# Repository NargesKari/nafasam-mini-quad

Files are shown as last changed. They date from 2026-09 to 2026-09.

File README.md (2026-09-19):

# nafasam-mini-quad

A phone-to-ESP32 wireless control link for a quadcopter, built around a hand-specified binary protocol with a checksum, a kill switch, and a failsafe — the network layer a drone project needs before the flight controller is worth writing.

## What it does

- Runs the ESP32 as an open WiFi access point (`nafasm`) serving a touch-control web page straight from flash, so any phone can connect with no app install.
- The page has two virtual joysticks (left: throttle/yaw, right: pitch/roll), an ARM/DISARM button, status lights (link / IMU / armed) and a help panel. It polls `GET /control` every 100 ms.
- A 200 Hz FreeRTOS task on core 0 reads the MPU6050 directly over its registers (no library), estimates roll/pitch with a complementary filter, runs PID stabilisation, mixes for an X-configuration quad and drives four transistor-switched brushed motors with PWM.
- Safety: failsafe disarm after 500 ms of silence, arm refused with throttle up, motors off on any IMU error, crash-angle disarm.

See `docs/protocol.md` for the exact contract.

## Repo layout

- `firmware/nafasam_quad/` - Arduino sketch (`.ino`, `config.h` pins/PID/safety, `mpu6050.*` driver, generated `web_page.h`)
- `web/public/index.html` - control page (single source of truth)
- `hardware/` - schematics, PCB, datasheets, mechanical parts
- `docs/` - protocol
- `scripts/generate_web_header.py` - embeds the page into the firmware

## Getting started

Arduino IDE with the ESP32 core v3.x (no extra libraries), open `firmware/nafasam_quad/nafasam_quad.ino`, select an ESP32 Dev Module, upload. Power the drone flat and still: the gyro calibrates at boot.

If you edit the control page:

```bash
python3 scripts/generate_web_header.py   # then re-flash
```

Connect to the `nafasm` WiFi and open `http://192.168.4.1/`.

**First power-up: remove the propellers** and check each motor's direction and the sign of the stabilisation on the bench before any flight.

<!-- add screenshot/demo here -->

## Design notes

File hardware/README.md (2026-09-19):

# hardware

Everything physical: circuits, PCBs, parts.

- `schematics/` - motor driver circuits, power distribution, ESP32 wiring (KiCad/Fritzing/PDF exports)
- `pcb/` - board layouts and Gerber files
- `datasheets/` - ESP32, IMU, transistor, motor, battery datasheets
- `mechanical/` - frame, motor mounts, 3D-printable parts (STL/STEP)

# Wiring guide

Board: generic **ESP32-WROOM-32 DevKit, 30 pins**. Pin names below are the labels printed on the board, with the GPIO number in brackets. The source of truth for pins is `firmware/nafasam_quad/config.h`.

## 1. ESP32 <-> MPU6050 (GY-521 module)

| MPU6050 pin | ESP32 pin (board label) | Notes |
|---|---|---|
| VCC | **3V3** | 3.3 V, not VIN |
| GND | **GND** | |
| SDA | **RX2** (GPIO16) | I2C data |
| SCL | **TX2** (GPIO17) | I2C clock |
| AD0 | GND (or leave open) | I2C address 0x68 |
| INT, XDA, XCL | not connected | unused |

Pull-ups: one resistor from **SDA (GPIO16) to 3V3** and one from **SCL (GPIO17) to 3V3**, between 2.2k and 10k ideally (27k also works at the 100 kHz the firmware uses). Many GY-521 modules already include pull-ups; adding external ones in parallel is fine.

Mount the module flat, chip facing up, with the module's **X axis pointing to the nose** and **Y to the left**. If it is mounted differently the stabilisation signs must be remapped in `flightTask()`.

## 2. ESP32 -> motor drivers (PWM outputs)

Each motor has its own transistor stage. The ESP32 pin goes to the transistor **base/gate through a resistor**.

| Motor | Position | Spin | ESP32 pin (board label) |
|---|---|---|---|
| FL | front-left | CW | **D23** (GPIO23) |
| FR | front-right | CCW | **D5** (GPIO5) |
| RL | rear-left | CCW | **D18** (GPIO18) |
| RR | rear-right | CW | **D13** (GPIO13) |

Per-motor circuit (low-side switch):

```
Battery + ----------------+----------------+
                          |                |
                       [Motor]        [Diode] (flyback, cathode to battery +)
                          |                |
                          +----------------+
                          |
                  collector/drain
ESP32 GPIO --[R base]-- base/gate      transistor
                  emitter/source
                          |
Battery - / common GND ---+
```

Also add:
- **Base/gate resistor** (about 1k for a BJT is typical; size it for your transistor and motor current) from GPIO to base/gate.
- **Pull-down** (about 10k) from base/gate to GND. This matters most on **GPIO5**, a boot-strapping pin that can pulse during boot and would briefly spin the motor.
- **Flyback diode** across every motor (anode on the transistor side). Without it the motor's voltage spikes can destroy the transistor and reset the ESP32.
- **Noise-filter capacitor** across each motor terminals (as planned; ceramic 100 nF is typical).
- Make sure each transistor can handle the motor's **stall current**, with margin.

Spin direction is fixed by how each motor is wired/mounted (the firmware never reverses a motor). If a motor spins the wrong way, swap its two motor wires.

## 3. Battery

The battery type is not fixed by the code, so pick the option that matches yours:

| Connection | Goes to |
|---|---|
| Battery **+** | motor **+** terminals (all four, via a fuse/switch ideally) and the ESP32 power input (see below) |
| Battery **-** | **ESP32 GND**, MPU6050 GND and all transistor emitters/sources |

**All grounds must be common** (battery -, ESP32 GND, MPU6050 GND, every transistor emitter). If they are not joined, the PWM signal has no reference and the motors will misbehave.

Powering the ESP32:
- Battery gives **about 5 V** (e.g. a 5 V regulator/boost stage, or USB power bank): connect to **VIN** (5 V) and GND.
- Battery is a **single 3.7 V LiPo**: the DevKit's on-board regulator needs about 5 V at VIN, so use a boost converter to 5 V into **VIN**, or a 3.3 V regulated supply into the **3V3** pin (bypasses the on-board regulator; never do both at once).
- Do **not** connect a battery above 6 V directly to VIN.
- Never connect USB and an external supply to VIN at the same time without a diode.

Motor current spikes can brown out the ESP32. Put a **large capacitor (about 470 uF or more)** across the battery rails near the ESP32 and, if resets still occur, a separate supply/regulator for the ESP32.

## 4. Quick checklist before first power-up

1. Remove the propellers.
2. Check continuity: MPU SDA -> GPIO16, SCL -> GPIO17, and each motor pin against the table above.
3. Confirm no short between battery + and -, and that all grounds are joined.
4. Power on with the drone flat and still (the gyro calibrates at boot); wait for the **IMU** light on the web page.
5. Connect to the `nafasm` WiFi, open `192.168.4.1`, and test each motor with low throttle before flying.

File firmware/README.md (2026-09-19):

# firmware

ESP32-S3 firmware for the Nafasam Mini Quadcopter.

- [`nafasam_quad/`](nafasam_quad/): Arduino sketch directory. Open [`nafasam_quad/nafasam_quad.ino`](nafasam_quad/nafasam_quad.ino) in Arduino IDE.
- [`nafasam_quad/README.md`](nafasam_quad/README.md): **Hardware pinout and port connection guide** for ESP32-S3, MPU-6050, motors, battery ADC, and programmer.
- [`nafasam_quad/config.h`](nafasam_quad/config.h): Tunable flight control, PID, PWM, and Wi-Fi constants.
- [`nafasam_quad/web_page.h`](nafasam_quad/web_page.h): Auto-generated web interface header (regenerate with `python3 scripts/generate_web_header.py`).

No external Arduino libraries required (uses native ESP32 core v3.x: `WiFi`, `Wire`, `esp_http_server`).

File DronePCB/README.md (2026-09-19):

# DroneFC — engineering prototype A0

Open **design/DroneFC.kicad_pro** in KiCad 10. The project includes an editable seven-page schematic, a four-layer PCB, and local symbol/footprint libraries. The local libraries make the project portable.

**This is a prototype design, not a flight-tested or production-qualified controller. Read reports/validation-summary.json for the latest checks. Do not fabricate from an intermediate routing file.**

## Design choices

- ESP32-S3-MINI-1-N4R2: soldered module with 4 MB flash and 2 MB PSRAM. The module integrates RF circuitry and a PCB antenna. A bare ESP32 silicon implementation would require additional RF, clock and memory design.
- MPU-6050 bare QFN chip, I2C address 0x68. The auxiliary sensor bus and reserved pins are intentionally unused.
- Four AO3400A low-side motor switches, four SS34 flyback diodes, 100-ohm gate resistors, and 10-kilohm gate-to-source pulldowns.
- One 700 mAh, 20C, 1S LiPo. The advertised continuous discharge calculation is 0.7 Ah × 20 = 14 A; it does not establish the battery's real internal resistance or transient capability.
- TPS63021 fixed 3.3 V buck-boost converter for electronics, with a 1.5 uH inductor, two 10 uF input capacitors, three 22 uF output capacitors, and 100 nF control-supply bypass. Target electronics load is up to 1 A at battery voltage ≥3.0 V, subject to thermal/transient testing.
- TLV70028 and TLV70012 regulators provide the camera's 2.8 V and 1.2 V rails.
- A 10-ohm/1 uF filter feeds the IMU; local VDD, VLOGIC, REGOUT and CPOUT capacitors are 100 nF, 10 nF, 100 nF and 2.2 nF respectively. CPOUT uses a 50 V-rated capacitor.
- No charging circuit, SD card slot, USB socket, development-board headers, or flash LED. Programming uses solder pads and an external 3.3 V UART adapter.

## Mechanical and stackup intent

PCB outline: **50 × 50 mm**, nominal **0.8 mm** FR4, four copper layers. This is the first layout size, not a claim of minimum achievable size or mass. The antenna end of the ESP32 module extends beyond the PCB outline, so the assembled envelope is larger than 50 mm in that direction.

Layers: front signals/components, inner ground, inner battery distribution, back signals. Two camera signals (PCLK and RESET) also use the battery layer with clearance around them; the ground plane remains continuous. Ground and battery use solid connections to the inner planes. The motor-current pads use multiple vias. The final copper thickness, stackup, minimum spacing and via process must be agreed with the board manufacturer. The thermal/current assumptions require approximately 35 um finished copper on the power planes and outer layers; do not silently substitute thinner inner copper.

U2 uses the local TI_DSJ14_TPS63021 footprint, with a 1.58 × 2.85 mm exposed ground pad checked against TI drawing 4208549-3/E. Its peripheral lands are slightly enlarged relative to TI's example. Segmented paste covers approximately 65% of the exposed pad. Have the assembler qualify stencil thickness and via-in-pad treatment, including the module ground pads and the regulator ground connection. This is not a qualified assembly process.

Four M2 clearance holes use a nominal 44 × 26 mm spacing. Confirm that this pattern fits the frame. Keep the module antenna free of battery, carbon fibre, motors and wiring. The PCB is a controller mounted to a frame, not a structural motor-support plate.

## Camera compatibility

J3 uses **Hirose FH12-24S-0.5SH(55)**, a 24-pin, 0.5 mm pitch, bottom-contact FPC connector. Its electrical pinout follows the OV2640 interface shown in the AI-Thinker ESP32-CAM v1.6 reference schematic archived in references/ESP32_CAM_V1.6.pdf.

Buy only a camera flex assembly with this exact pinout. “OV2640” alone does not specify the connector pinout, contact side, flex thickness, lens clearance or power rails. The final camera assembly has not been selected from a seller. **The seller's flex drawing must be checked before fabrication.** The provided connector is not a generic plug for every ESP32 camera.

The camera's Y2–Y9 lines form D0–D7. Y0/Y1 and pin24 are unused. Camera I/O runs at 3.3 V, analog at 2.8 V and core at 1.2 V, consistent with the referenced assembly. See pin-map.json for the exact connections.

## Motor and battery connections

J2 pin1 is battery positive, pin2 is ground. J4–J7 pin1 is motor positive (VBAT), pin2 is the switched motor negative. SS34 cathodes connect to VBAT and anodes to motor negative. AO3400A pin1 is gate, pin2 source, pin3 drain.

**C101–C104 are off-board components:** solder one 100 nF, 16 V ceramic directly across each motor's terminals. Their presence in the BOM is intentional; they have no PCB footprints. C25–C28 are separate local 10 uF rail-decoupling capacitors near the motor drivers. C11 is a low-ESR 220 uF bulk capacitor. Its exact manufacturer part number, ripple rating, ESR and height remain a sourcing check; its allocated package is 6.3 × 5.8 mm.

The linked ECA listing describes 1.74 A as maximum loaded current. Four motors at that figure draw 6.96 A, excluding electronics. Stall/startup current is not specified by that figure. Measure it with current limiting and appropriate test equipment. Do not infer MOSFET, diode or battery stall survival from their headline current ratings.

AO3400A's specified 48 milliohm maximum at 2.5 V gate drive gives approximately 0.145 W conduction loss per motor at 1.74 A and continuous on-time at the datasheet reference temperature. Hot resistance, switching loss and flyback-diode dissipation increase the actual thermal load. This calculation is not a thermal qualification.

There is no reverse-polarity protection, battery charger or hardware LiPo cutoff on this board. Confirm polarity before connection, use an external 1S charger, and disconnect the battery after use. Battery voltage monitoring is available to firmware through a 100k/100k divider and 100 nF filter. The nominal ADC scale factor is 2, with calibration still required.

## Programming and firmware requirements

J1 pads, in order: GND, 3V3, UART_TX, UART_RX, BOOT, ESP_EN. Use **3.3 V logic**. Connect adapter TX to board RX and adapter RX to board TX. With the battery powering the board, use J1's 3V3 as a reference only; do not connect a second driven supply. Hold BOOT low while pulsing ESP_EN low to enter the ROM loader.

The included firmware header only defines hardware pins. It is not flight-control firmware. Before flying, implement and test local IMU sampling, calibration, attitude estimation, motor mixing, arming, link-loss response, watchdog response and low-battery handling. Flight stabilization must run locally; Wi-Fi carries commands/video rather than providing the timing of the stabilization loop. Keep camera processing from delaying the control loop.

All motor PWM outputs must initialize low. Establish a measured control-loop budget with camera streaming enabled. A fresh 1S cell reaches 4.2 V; the motors are listed as nominal 3.7 V. Confirm their permitted supply and use a battery-aware duty limit as appropriate. An average-voltage duty limit does not limit instantaneous stall current.

## Bench acceptance before flight

1. Inspect soldering and check supply resistance and polarity without battery connected. Start on a current-limited supply with motors disconnected.
2. Sweep battery input over the intended operating range and verify 3.3 V, 2.8 V, 1.2 V and IMU supply voltage, including camera/Wi-Fi transients.
3. Read MPU-6050 identity, check stationary gyro/accelerometer readings and confirm axis orientation. Check camera frames and the UART boot process.
4. With propellers removed, verify each motor remains off at boot/reset and test PWM individually. Then use a restrained thrust test to establish propeller load, startup current, voltage sag and component temperature.
5. Verify arming, loss-of-link response, watchdog reset and low-battery behavior before any flight. Establish thrust margin using the actual all-up mass.

## Sources

- [ESP32-S3-MINI module datasheet](https://documentation.espressif.com/esp32-s3-mini-1_mini-1u_datasheet_en.html)
- [Espressif camera driver and supported sensors](https://github.com/espressif/esp32-camera)
- [AI-Thinker ESP32-CAM v1.6 reference schematic, hosted by Seeed](https://github.com/SeeedDocument/forum_doc/blob/master/reg/ESP32_CAM_V1.6.pdf)
- [MPU-6000/6050 manufacturer specification](https://invensense.tdk.com/wp-content/uploads/2015/02/MPU-6000-Datasheet.pdf)
- [AO3400A manufacturer specifications](https://www.aosmd.com/products/mosfets/low-voltage-mosfets-12v-30v/ao3400a)
- [TPS63020/21 manufacturer datasheet](https://www.ti.com/lit/ds/symlink/tps63020.pdf)
- [XFL4020 inductor drawing](https://www.coilcraft.com/getmedia/50632d43-da1b-4cdb-8ab4-3029cab51df3/xfl4020.pdf)
- [Hirose camera connector](https://www.hirose.com/product/p/CL0586-0521-0-55)
- [ECA 8520 motor listing](https://eshop.eca.ir/موتور-coreless/6933-موتور-coreless-سایز-8520.html)

## Project contents

- design/DroneFC.kicad_pro, .kicad_sch and .kicad_pcb: editable KiCad project.
- BOM.csv: individual component values, packages and sourcing notes.
- design_manifest.json: component/net design intent; the PCB contains the final adjusted placement.
- pin-map.json and drone_pins.h: interface mapping.
- reports/: electrical, physical and connectivity checks.
- preview/: schematic and board previews.
- tools/ (working directory only, omitted from the delivery archive): development helpers and project-local routing tools. These contain intermediate design assumptions. Re-running build_design.py with --pcb replaces the board with its initial unrouted placement. Preserve the final PCB and local libraries before regenerating.

## Validation and delivery

The final routed PCB passes the configured KiCad electrical and physical checks with zero reported violations and zero unconnected items. An independent exported-netlist comparison matches all 240 connected component pins between schematic and PCB. The JSON reports list the checks that KiCad ignores under the project settings; a clean report does not establish thermal performance, signal integrity or flight suitability.

DroneFC-prototype-A0.zip contains the editable design, local libraries, component list, pin mapping, final reports and previews. No manufacturing release is included: camera flex compatibility, C11 sourcing, assembly process and manufacturer stackup still require confirmation. Actual motor startup/stall current, rail transients, thermal behavior and thrust margin require hardware tests. Board mass and efficiency have not been measured.

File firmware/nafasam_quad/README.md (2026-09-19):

# Nafasam Mini Quad - Firmware & Hardware Connection Guide

This directory contains the Arduino flight controller sketch for the **Nafasam Mini Quadcopter**, designed for the **ESP32-S3-MINI-1-N4R2** microcontroller and the **DroneFC PCB Revision A0**.

---

## 1. Physical Layout & Motor Orientation

The quadcopter uses an **X-Configuration**. The front of the drone corresponds to the top edge of the DroneFC PCB where the ESP32-S3 antenna extends.

```text
                  FRONT / NOSE
             (ESP32 Antenna Side)
                      ▲
                      │
     [Motor 1: FL]          [Motor 2: FR]
        GPIO 39                GPIO 40
        (CW ↻)                 (CCW ↺)
            \                /
             \    [U3]      /
              \  MPU-6050  /
               \  Center  /
                \        /
                 \      /
     [Motor 3: RL]          [Motor 4: RR]
        GPIO 41                GPIO 42
        (CCW ↺)                (CW ↻)
                      │
                      ▼
                 REAR / TAIL
            (Camera FPC Connector)
```

---

## 2. Complete Port & Pin Mapping Table

| Subsystem | Function / Signal | ESP32-S3 GPIO | PCB Net | Connector / Part Reference | Notes |
|---|---|---|---|---|---|
| **Motors (8520)** | Motor 1: Front-Left (FL) | **GPIO 39** | `PWM1` | `J4` / `Q1` (AO3400A) | Spin: Clockwise (**CW**). Switched to `MOTOR1_NEG`. |
| **Motors (8520)** | Motor 2: Front-Right (FR) | **GPIO 40** | `PWM2` | `J5` / `Q2` (AO3400A) | Spin: Counter-Clockwise (**CCW**). Switched to `MOTOR2_NEG`. |
| **Motors (8520)** | Motor 3: Rear-Left (RL) | **GPIO 41** | `PWM3` | `J6` / `Q3` (AO3400A) | Spin: Counter-Clockwise (**CCW**). Switched to `MOTOR3_NEG`. |
| **Motors (8520)** | Motor 4: Rear-Right (RR) | **GPIO 42** | `PWM4` | `J7` / `Q4` (AO3400A) | Spin: Clockwise (**CW**). Switched to `MOTOR4_NEG`. |
| **IMU (MPU-6050)** | I2C Serial Data (SDA) | **GPIO 33** | `IMU_SDA` | `U3` Pin 24 | Dedicated I2C bus with pull-up resistor. |
| **IMU (MPU-6050)** | I2C Serial Clock (SCL) | **GPIO 34** | `IMU_SCL` | `U3` Pin 23 | Dedicated I2C clock (400 kHz Fast-Mode). |
| **IMU (MPU-6050)** | Interrupt Line (INT) | **GPIO 21** | `IMU_INT` | `U3` Pin 12 | Active-high motion interrupt. |
| **Battery Monitor** | 1S LiPo Sense (ADC) | **GPIO 1** | `VBAT_SENSE` | `R2`/`R3` Voltage Divider | 100k / 100k divider (2:1 ratio). Max 4.2V $\rightarrow$ 2.1V at ADC. |
| **UART Programmer** | Transmit (TXD) | **GPIO 43** | `UART_TX` | `J1` Pad 3 | Connect to external 3.3V UART adapter **RX**. |
| **UART Programmer** | Receive (RXD) | **GPIO 44** | `UART_RX` | `J1` Pad 4 | Connect to external 3.3V UART adapter **TX**. |
| **UART Programmer** | Boot Mode Button/Pad | **GPIO 0** | `BOOT` | `J1` Pad 5 | Hold LOW while pulsing `ESP_EN` to flash. |
| **UART Programmer** | Chip Enable / Reset | `ESP_EN` | `ESP_EN` | `J1` Pad 6 | Pull LOW briefly to reset ESP32. |
| **Power Supply** | Main System 3.3V | `3V3` | `3V3` | `U2` (TPS63021) | Buck-boost converter output feeding ESP32 & sensors. |
| **Power Supply** | Common Ground | `GND` | `GND` | All GND pads | Ground plane common to battery, MCU, IMU, and MOSFET sources. |

---

## 3. Subsystem Wiring & Connection Details

### 3.1 8520 Coreless Brushed Motor Driver Circuit
Each motor is driven by a low-side AO3400A N-Channel MOSFET:
- **Gate**: Driven by ESP32-S3 GPIO via a $100\,\Omega$ series resistor (`R1`, `R18`, `R19`, `R20`), with a $10\,\text{k}\Omega$ pull-down to GND.
- **Drain**: Connects to the motor negative terminal (`MOTORx_NEG`).
- **Source**: Directly connected to solid board ground (`GND`).
- **Flyback Diode**: An SS34 Schottky diode is connected in parallel with each motor (Cathode to `VBAT`, Anode to `MOTORx_NEG`) to absorb inductive kickback spikes.
- **RF Noise Filter**: Solder a $100\,\text{nF}$, $16\,\text{V}$ ceramic capacitor (`C101`–`C104`) directly across the terminal wires of each 8520 motor.

### 3.2 InvenSense MPU-6050 IMU
- **I2C Address**: `0x68` (Pin `AD0` connected to `GND`).
- **Orientation on PCB**:
  - `+X` points to **Right**
  - `+Y` points to **Forward / Nose**
  - `+Z` points **Up**
- **Power**: Filtered `3V3` rail via a $10\,\Omega$ resistor and local decoupling capacitors ($100\,\text{nF}$ + $1\,\mu\text{F}$).

### 3.3 Battery Voltage Measurement
- Connect 1S LiPo battery positive terminal to `J2` Pin 1 (`VBAT`) and negative terminal to `J2` Pin 2 (`GND`).
- `VBAT_SENSE` routes through a 2:1 resistive voltage divider ($R_1 = 100\,\text{k}\Omega$, $R_2 = 100\,\text{k}\Omega$, filtered by a $100\,\text{nF}$ capacitor).
- Calculation in firmware:
  $$\text{Voltage} = \frac{\text{analogReadMilliVolts}(1) \times 2.0}{1000}$$

### 3.4 Programmer Pads (`J1`)
The board has a 6-pad programming interface for an external 3.3V USB-to-UART adapter:

```text
 Pad 1: GND      ─── Connect to Programmer GND
 Pad 2: 3V3      ─── Reference ONLY (Do NOT supply external power when battery is connected)
 Pad 3: UART_TX  ─── Connect to Programmer RX
 Pad 4: UART_RX  ─── Connect to Programmer TX
 Pad 5: BOOT     ─── Hold to GND while resetting to enter download mode
 Pad 6: ESP_EN   ─── Pull to GND briefly to reset the MCU
```

---

## 4. Arduino IDE Upload Instructions

1. Open `nafasam_quad.ino` in Arduino IDE 2.x.
2. Under **Tools $\rightarrow$ Board $\rightarrow$ esp32**, select **ESP32S3 Dev Module**.
3. Recommended settings:
   - **Flash Size**: `4MB (32Mb)`
   - **PSRAM**: `OPI PSRAM` (or Disabled if unused)
   - **Upload Speed**: `115200` or `921600`
   - **USB Mode**: `Hardware CDC and JTAG`
4. Connect programmer pads (`TX`, `RX`, `GND`). Hold `BOOT` low, pulse `ESP_EN` low, release `BOOT`, then click **Upload**.

---

## 5. First Flight Bench Acceptance Checklist

> [!CAUTION]
> **ALWAYS REMOVE ALL PROPELLERS** during bench testing and calibration!

1. **Visual & Continuity Inspection**:
   - Verify no short circuit between `VBAT` and `GND`.
   - Verify continuity on motor gate pins and IMU `SDA` (GPIO 33), `SCL` (GPIO 34).
2. **Boot IMU Calibration**:
   - Place the drone completely **flat and still** before applying battery power.
   - The gyro automatically averages 300 samples to establish bias offsets. The `IMU` indicator will turn green once calibration passes.
3. **Wi-Fi Connection**:
   - On your smartphone, connect to the Wi-Fi access point: **`Nafasam`** (open network).
   - Navigate to `http://192.168.4.1/`.
4. **Motor Spin Test**:
   - Arm the quad at zero throttle.
   - Slowly raise the throttle slider to verify all 4 motors spin.
   - Confirm proper rotation direction:
     - Motor 1 (FL): **Clockwise (CW)**
     - Motor 2 (FR): **Counter-Clockwise (CCW)**
     - Motor 3 (RL): **Counter-Clockwise (CCW)**
     - Motor 4 (RR): **Clockwise (CW)**
   - *If any motor spins in reverse, swap its two motor wire leads on the PCB.*
5. **Stabilisation Direction Check**:
   - With low throttle active, tilt the drone forward by hand: front motors should speed up to push the nose back up.
   - Tilt the drone to the right: right motors should speed up to level the frame.

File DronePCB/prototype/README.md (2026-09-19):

# Drone perfboard prototype P1

This is a separate soldered **برد سوراخ‌دار** build. Open **Perfboard.kicad_pro** in KiCad. The original SMD PCB project is unchanged. The schematic has four circuit sheets plus an index. Matching net labels mean an electrical connection; the wire-list.md file lists every endpoint.

“MPU5060” is interpreted as the previously confirmed **MPU-6050**. Buy an assembled MPU-6050 breakout, not the bare QFN chip. This is a module/through-hole construction, not a literal all-DIP circuit: the ESP32 and MPU chips are already mounted on their modules, and AO3400A needs a SOT-23 adapter.

## Exact module choices

- **U1: Freenove ESP32-S3-WROOM camera board, FNK0085, N8R8 or N16R8, with its supplied compatible OV2640 and 2.54 mm headers.** Do not substitute the eight-pin-per-side AI-Thinker ESP32-CAM or a board with a different pinout. Use the supplied flex directly in the board camera socket. The board already contains camera power circuits, ESP32 decoupling, memory, boot/reset and USB programming circuitry.
- **U2: Adafruit MPU-6050 breakout**, powered at VIN = 3.3 V from U1. Its documented regulator and level shifting support this connection. Leave its 3Vo regulator-output pin unconnected. A GY-521 is a possible locally available substitute, but is not electrically standardized: first check its schematic, supply regulator and pullup rail. Do not simply put 5 V on its I2C pins. If powered at 3.3 V, verify the actual MPU VDD is within its 2.375–3.46 V operating range under load. The default drawing uses the Adafruit module.
- **U3: Pololu U3V40F5, fixed 5 V boost module.** It feeds only the electronics. If buying another boost module, require demonstrated 5 V / 1 A output from 3.0 V input, startup at or below 3.0 V, and acceptable ripple. An advertised switch/input-current number is not an output-current rating. The reference module is 15.2 × 15.2 mm and weighs 1.5 g. [Pololu specifications](https://www.pololu.com/product/4012).

For local sellers, useful search terms are «برد ESP32-S3 WROOM دوربین دار»، «ماژول MPU6050»، «تبدیل SOT23 به DIP»، «دیود شاتکی 1N5822» and «برد سوراخ دار دو طرفه 2.54 میلی متر». Product names alone do not establish matching pinouts.

## Signal wiring

The custom module symbols use printed **header labels as pin identifiers**. Their drawn positions and identifiers are not a footprint or sequential physical pin numbering. Use references/Freenove-pinout.png when finding the header pins.

- GPIO14 → R1 100 Ω → Q1 gate: motor 1.
- GPIO21 → R2 100 Ω → Q2 gate: motor 2.
- GPIO47 → R3 100 Ω → Q3 gate: motor 3.
- GPIO39 → R4 100 Ω → Q4 gate: motor 4.
- GPIO41 → IMU SDA. R9 4.7 kΩ pulls this line to 3.3 V.
- GPIO42 → IMU SCL. R10 4.7 kΩ pulls this line to 3.3 V.
- GPIO40 ← IMU INT. Configure and verify the IMU data-ready interrupt in firmware.
- IMU AD0 → GND, selecting address 0x68. IMU VIN → 3.3 V; IMU GND → common GND.
- GPIO1 ← battery divider midpoint: VBAT → R11 100 kΩ → midpoint → R12 100 kΩ → GND. C13 100 nF connects midpoint to GND. The nominal reading is half the battery voltage; calibrate ADC readings against a meter.

The camera's built-in connections occupy GPIO4–13 and GPIO15–18. GPIO39 and GPIO40 are normally associated with the SD socket, so **leave the SD socket empty and do not initialize SD**. Do not enable external GPIO JTAG on the reused pins. Boot straps, GPIO35–37 memory pins, USB GPIO19/20, UART GPIO43/44 and RGB LED GPIO48 are not assigned to motor outputs. The included header differs from the original custom PCB pin map.

The Adafruit board already has I2C pullups; the additional 4.7 kΩ resistors make a stronger effective pullup for short perfboard wiring. Start I2C at 100 kHz, check readings and rise times, then validate 400 kHz if required by the control-loop budget. Keep SDA/SCL short, with a nearby ground return.

## Power and each motor channel

Battery positive is **VBAT**, 3.0–4.2 V operating-test range for a 1S pack. Battery negative is GND. Motors connect directly to VBAT; never connect them to boosted 5 V or the ESP board power pins.

1. Battery + goes to each motor +, each diode's banded cathode, C9 positive and U3 VIN. Both VIN pads on the reference boost module may be wired in parallel.
2. Battery − goes to all four Q sources and, by a separate electronics return wire, U3 GND, U1 GND and IMU GND. Connect both GND pads on U3 where practical. Make the motor-current returns meet the battery return without flowing through the IMU/ESP ground wiring.
3. U3 VOUT goes to U1's **5V** pin. Leave U3 EN open; its onboard pullup enables it. U1's **3V3 output** supplies U2 and the I2C pullups.
4. For each AO3400A: **pin 1 = gate, pin 2 = source, pin 3 = drain**. Gate connects through the 100 Ω resistor to its PWM pin. Its 10 kΩ resistor connects gate directly to source. Drain connects to motor − and the diode's unbanded anode. Check adapter markings against the transistor pins with continuity testing; adapter header order is not universal.
5. D1–D4 are **1N5822, 3 A / 40 V Schottky**, band towards VBAT. Keep each diode and MOSFET loop short. The MOSFET's internal diode does not replace this flyback diode.
6. C1–C4, 100 nF ceramic, solder directly across the four motor terminals. C5–C8, 10 µF electrolytic, connect VBAT to GND near each driver; these are different connections from the motor capacitors.
7. C9, 470 µF low-ESR electrolytic, sits at the battery distribution point. C10, 47 µF, sits at U3 VIN. C11, 100 µF, and C12, 100 nF, sit at U1's 5 V input. C14, 100 nF, and C15, 10 µF, sit at U2 VIN. Observe electrolytic polarity.

Unplug the battery before connecting a normal USB cable for programming; this avoids unknown USB/external-supply backfeeding on board variants. Program with propellers removed. Disconnect USB before reconnecting the battery. There is no charging circuit, reverse-polarity protection or independent LiPo motor cutoff in this prototype. U3 EN does not completely disconnect its output. Unplug the battery after use.

## Perfboard construction

Use a 2.54 mm **isolated-pad** solderable perfboard, around 60 × 80 mm as a starting piece, trimmed after checking the actual module sizes. This is an arrangement guide rather than a hole-by-hole layout: module dimensions and SOT-23 adapters vary by seller. Never assume adjacent isolated pads are electrically connected. Stripboard requires a separate cut-track plan and is not the drawing's assumption.

Place the camera/ESP antenna at an outer edge, IMU close to the frame centre, and boost converter away from the IMU. Put the four motor drivers near their wire exit points. Position the battery bulk capacitor next to the main power junction. Keep battery, copper bus wires and carbon fibre away from the antenna. Mechanically secure modules and battery, add wire strain relief, and insulate the underside.

Use short 20 AWG silicone main battery wires (18 AWG for longer runs or higher measured currents), about 24 AWG for short individual motor branches, and 28–30 AWG for signals. Size the final wiring for measured startup current and acceptable voltage drop. Use soldered copper bus wire for motor distribution: **do not carry motor current through loose Dupont jumpers, solderless breadboards, thin adapter traces, or chains of perfboard solder bridges**. Inspect adapter copper and reinforce the drain/source routes as needed. Four motor currents total 6.96 A at the stated 1.74 A each, before electronics; stall current can be higher.

Sockets are convenient for bench changes. For flying, direct soldered module headers or properly secured sockets are preferable to loose plug-in leads. Reusing AO3400A on tiny adapters provides much less predictable cooling than the custom PCB, so temperature tests are necessary. At 1.74 A, the datasheet's 48 mΩ limit at 2.5 V gate drive implies about 0.145 W per FET at its reference temperature, before switching loss and hot-resistance increase. This is not a continuous-current approval for an adapter.

## Flight-test conditions

Perfboard can support prototyping and a restrained motor test. Flight capability cannot be established from the schematic: the development board, adapters, axial diodes, wiring and sockets add weight. Weigh the full aircraft and measure thrust with the actual propellers and battery; a total static thrust around twice takeoff weight is a useful design target for control margin, not a guarantee of stable flight.

Before flight, verify rails while all motors and camera/Wi-Fi operate, MOSFET/diode/connector temperatures, battery sag, IMU vibration response and motor directions. Begin electrically with motors disconnected, then test without propellers, followed by a restrained thrust test. Match two CW and two CCW propellers/motors to the frame and firmware mixer. Motor numbering here is electrical only; it does not assign frame corners or rotation directions.

Firmware must implement local stabilization, IMU calibration and axis mapping, an arming state, all-PWM-low startup, loss-of-link disarming, watchdog handling and battery monitoring. The motor timer/channel assignments must not overwrite the camera XCLK timer. Start with roughly 20 kHz motor PWM and validate heating/noise and firmware timing; tune if needed. The pin header supplied here is not flight-control software. A fresh cell reaches 4.2 V, so verify the motors' allowable supply and duty limits. Wi-Fi commands/video must not determine stabilization timing.

## Sources and checks

- [Freenove FNK0085 documentation](https://docs.freenove.com/projects/fnk0085/en/latest/fnk0085/codes/C/Preface.html)
- [Manufacturer pinout drawing](https://github.com/Freenove/Freenove_ESP32_S3_WROOM_Board/blob/main/ESP32S3_Pinout.png)
- [Manufacturer camera pin definitions](https://github.com/Freenove/Freenove_ESP32_S3_WROOM_Board/blob/main/C/Sketches/Sketch_07.1_CameraWebServer/camera_pins.h)
- [Adafruit MPU-6050 breakout pinouts](https://learn.adafruit.com/mpu6050-6-dof-accelerometer-and-gyro/pinouts)
- [TDK MPU-6050 specification](https://invensense.tdk.com/wp-content/uploads/2015/02/MPU-6000-Datasheet.pdf)
- [AO3400A specifications](https://www.aosmd.com/products/mosfets/low-voltage-mosfets-12v-30v/ao3400a)
- [Vishay 1N5822](https://www.vishay.com/en/product/88526/)

See validation.json for the schematic export/net comparison and ERC result. These checks verify the documented circuit's connections, not the wiring or performance of hardware assembled later. No routed PCB or automatic physical footprint mapping is supplied for this module-interface schematic.

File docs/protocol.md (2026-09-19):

# Communication Protocol (v2)

Contract between the control page (`web/public/index.html`) and the ESP32 firmware. If this changes, update this file first, then both sides.

## Transport

| | |
|---|---|
| Network | ESP32 SoftAP, SSID `nafasm` (open by default, see `AP_PASSWORD` in `firmware/nafasam_quad/config.h`) |
| Address | `http://192.168.4.1` (port 80, `esp_http_server`) |

## Endpoints

### `GET /`
Serves the control page (embedded in flash as `web_page.h`).

### `GET /control?throttle=T&yaw=Y&pitch=P&roll=R&armed=A`

Sent by the page every 100 ms.

| Param | Range | Meaning |
|---|---|---|
| `throttle` | 0..100 | 0 = motors off |
| `yaw` | -100..100 | right = clockwise, commands a yaw *rate* (max 120 deg/s) |
| `pitch` | -100..100 | forward = +, commands an *angle* (max 25 deg) |
| `roll` | -100..100 | right = +, commands an *angle* (max 25 deg) |
| `armed` | 0/1 | requested arm state |

All five parameters are required; a missing one returns `400` and changes nothing. Values outside the range are clamped.

Response: `{"armed":0|1,"imu":0|1}` — the state the flight task is *actually* in (not the requested one) and whether the MPU6050 is working.

## Safety rules (enforced in firmware)

- **Failsafe:** no valid `/control` request for 500 ms → disarm and zero throttle. Re-arming then requires the page to send `armed=0` first.
- **Arm interlock:** arming is refused while `throttle > 5`; the page sees `armed:0` in the response and reverts the button.
- **IMU fault:** any MPU6050 read error turns all motors off immediately; after 5 consecutive errors the sensor is re-initialised and re-calibrated (board must be still).
- **Crash guard:** roll or pitch beyond 70 deg disarms.
- **Page hidden / closed:** the page disarms itself.
- Motors also stay off while `throttle < 3`.

## Flight loop (not part of the wire protocol)

200 Hz FreeRTOS task on core 0: MPU6050 registers over `Wire` → complementary filter (alpha 0.98) → PID on roll/pitch angle (D term from gyro rate) + P on yaw rate → X-configuration mixer → 1 kHz PWM via `ledcWrite`. Tunables are in `firmware/nafasam_quad/config.h`.

## Changes from v1

v1 used a 6-byte binary WebSocket frame at 50 Hz with an XOR checksum and KILL/CALIBRATE/ACRO flags. v2 replaces it with plain HTTP polling (no external async server library); KILL is now simply `armed=0`, and calibration happens automatically at boot.

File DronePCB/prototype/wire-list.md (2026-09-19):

# Perfboard point-to-point connections

Module pin identifiers below are **printed header labels**, not physical pin numbers. Q1-Q4 use the actual AO3400A pin numbers. All points on the same line connect together.

- **3V3**: U1.3V3, U2.VIN, R9.1, R10.1, C14.1, C15.1
- **5V**: U1.5V, U3.VOUT, C11.1, C12.1
- **GATE1**: Q1.1, R1.2, R5.1
- **GATE2**: Q2.1, R2.2, R6.1
- **GATE3**: Q3.1, R3.2, R7.1
- **GATE4**: Q4.1, R4.2, R8.1
- **GND**: U1.GND, U2.GND, U2.AD0, U3.GND, J1.2, R12.2, C13.2, C14.2, C15.2, C9.2, C10.2, C11.2, C12.2, Q1.2, R5.2, C5.2, Q2.2, R6.2, C6.2, Q3.2, R7.2, C7.2, Q4.2, R8.2, C8.2
- **IMU_INT**: U1.40, U2.INT
- **IMU_SCL**: U1.42, U2.SCL, R10.2
- **IMU_SDA**: U1.41, U2.SDA, R9.2
- **MOTOR1_NEG**: Q1.3, D1.2, J2.2, C1.2
- **MOTOR2_NEG**: Q2.3, D2.2, J3.2, C2.2
- **MOTOR3_NEG**: Q3.3, D3.2, J4.2, C3.2
- **MOTOR4_NEG**: Q4.3, D4.2, J5.2, C4.2
- **PWM1**: U1.14, R1.1
- **PWM2**: U1.21, R2.1
- **PWM3**: U1.47, R3.1
- **PWM4**: U1.39, R4.1
- **VBAT**: U3.VIN, J1.1, R11.1, C9.1, C10.1, D1.1, J2.1, C1.1, C5.1, D2.1, J3.1, C2.1, C6.1, D3.1, J4.1, C3.1, C7.1, D4.1, J5.1, C4.1, C8.1
- **VBAT_SENSE**: U1.1, R11.2, R12.1, C13.1

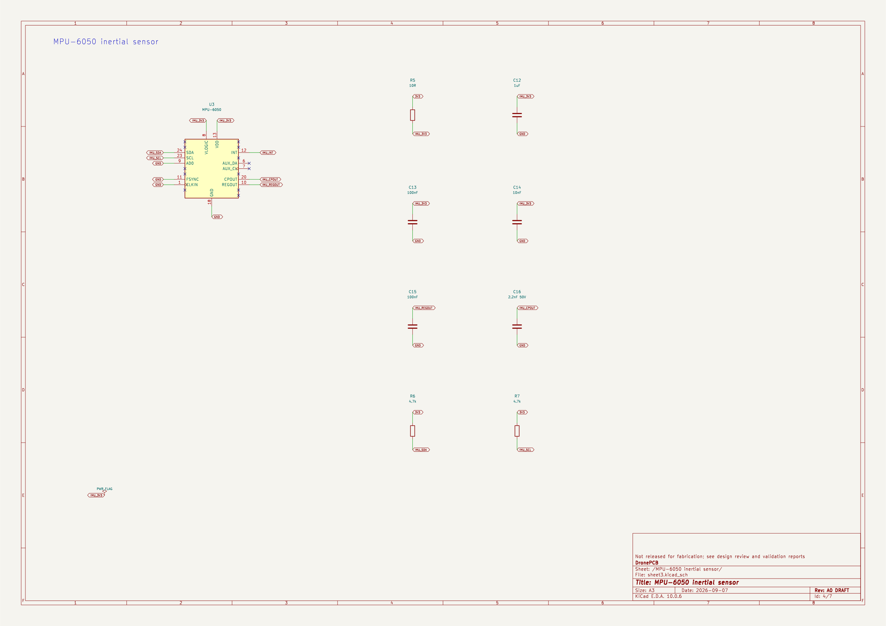
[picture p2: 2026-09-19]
DronePCB/preview/imu.png

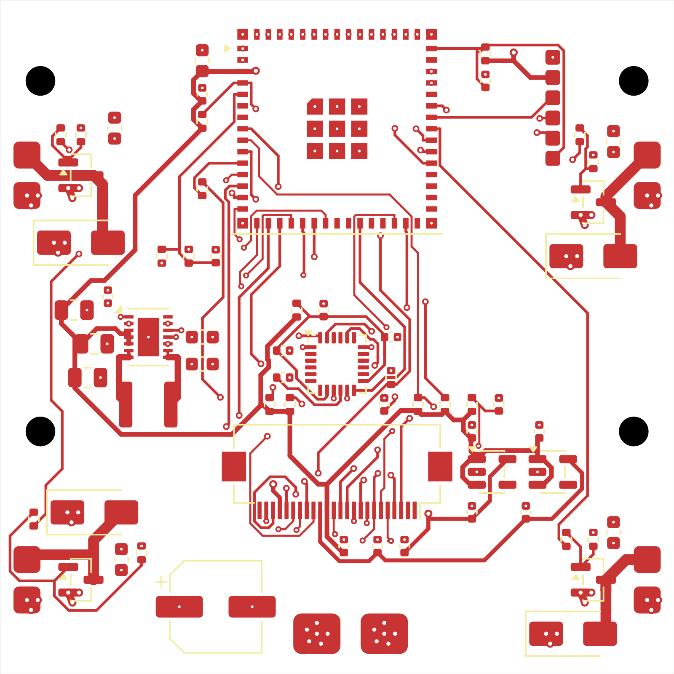
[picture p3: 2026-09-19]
DronePCB/preview/board-final.png

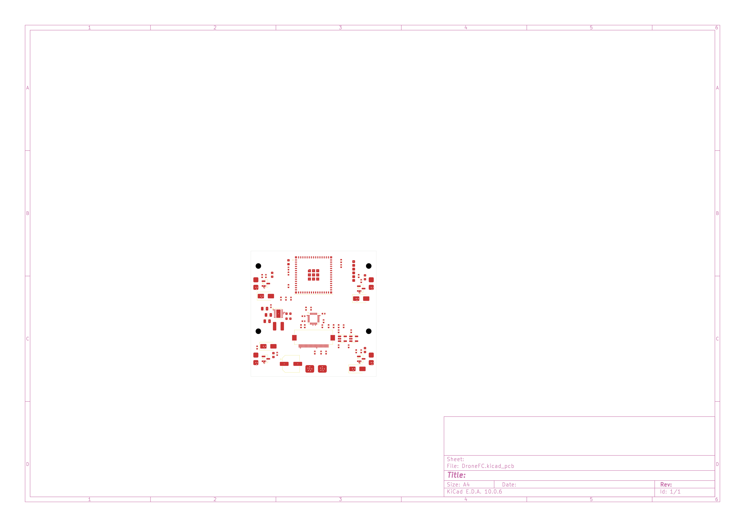
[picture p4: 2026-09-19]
DronePCB/preview/board.png

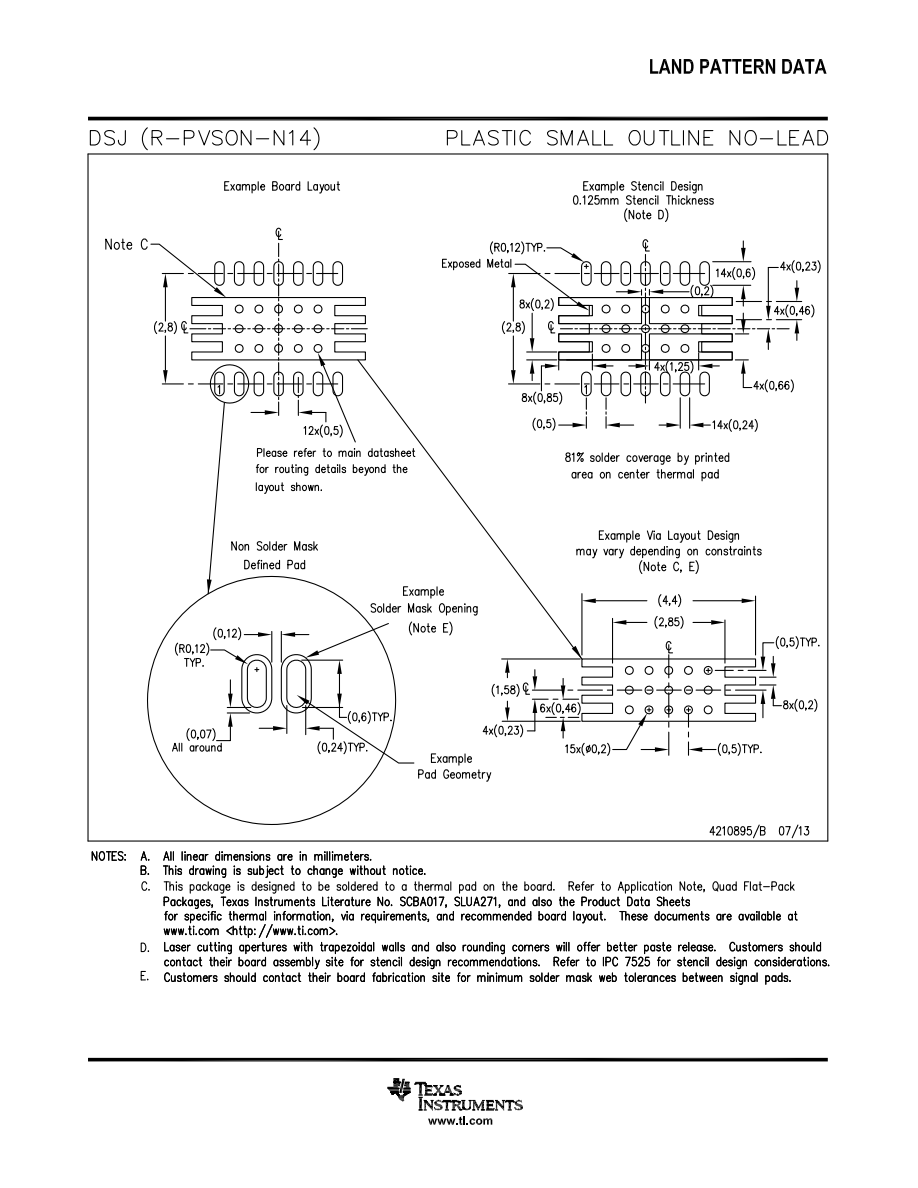
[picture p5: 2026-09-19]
DronePCB/preview/package-27.png

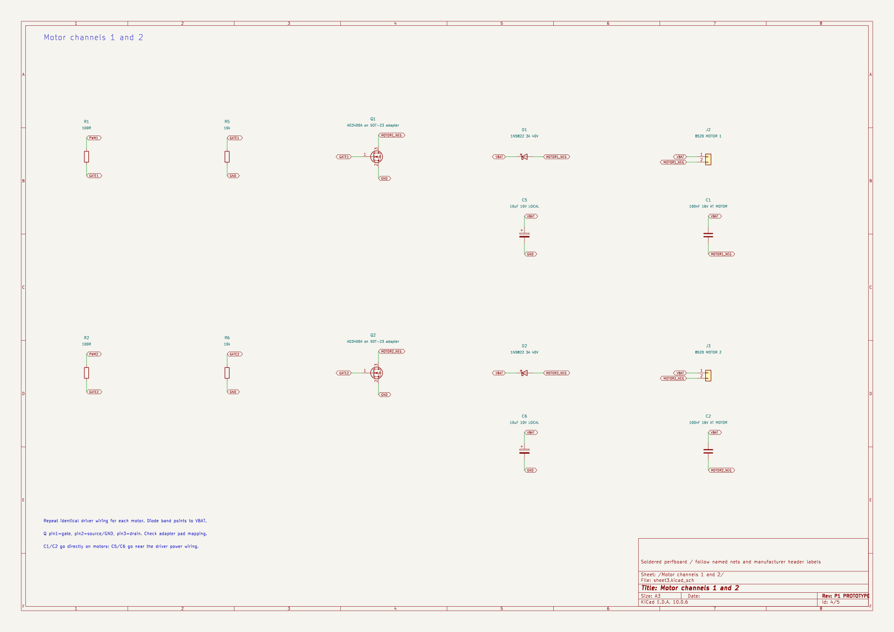
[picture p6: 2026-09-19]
DronePCB/prototype/preview/motor-drivers.png

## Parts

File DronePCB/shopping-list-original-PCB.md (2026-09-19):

# Shopping list — original SMD PCB A0

This is the grouped parts list for the original custom PCB, **not** the perfboard prototype. Use prototype/shopping-list.md for the module build. Fit quantities are exact from BOM.csv; buy quantities include inexpensive spares. Reuse motors/battery and shared frame/propeller/charger/wiring items from the prototype shopping list. Do not purchase these bare-chip support circuits for the module version.

Before ordering the custom PCB parts, confirm the selected camera flex matches the documented J3 pinout and choose the exact low-ESR bulk capacitor. Connector pads J1/J2/J4-J7 are solder pads already on the PCB, not purchased headers. A 3.3 V logic USB-UART programmer is required for this original board.

- [ ] **ESP32-S3-MINI-1-N4R2 — fit 1; buy 1.** U1. Package: RF_Module:ESP32-S2-MINI-1. 4MB flash / 2MB PSRAM; module antenna extends beyond top board edge
- [ ] **10uF — fit 7; buy 9.** C1, C5, C6, C25, C26, C27, C28. Package: Capacitor_SMD:C_0603_1608Metric. X7R, 10V; use specified voltage where marked
- [ ] **100nF — fit 9; buy 11.** C2, C4, C7, C13, C15, C21, C22, C23, C24. Package: Capacitor_SMD:C_0402_1005Metric. X7R, 10V; use specified voltage where marked
- [ ] **10k — fit 8; buy 10.** R1, R2, R10, R11, R17, R18, R19, R20. Package: Resistor_SMD:R_0402_1005Metric. 1%, 0402
- [ ] **1uF — fit 6; buy 8.** C3, C12, C17, C18, C19, C20. Package: Capacitor_SMD:C_0402_1005Metric. X7R, 10V; use specified voltage where marked
- [ ] **100k — fit 2; buy 5.** R3, R4. Package: Resistor_SMD:R_0402_1005Metric. 1%, 0402
- [ ] **TPS63021DSJR — fit 1; buy 1.** U2. Package: Drone:TI_DSJ14_TPS63021. Fixed3.3V; power-save mode; 1A electronics design target at VBAT>=3.0V subject to bench testing
- [ ] **1.5uH XFL4020-152MEC — fit 1; buy 1.** L1. Package: Drone:XFL4020. Coilcraft reference inductor; confirm exact suffix and DCR at sourcing
- [ ] **22uF — fit 3; buy 5.** C8, C9, C10. Package: Capacitor_SMD:C_0805_2012Metric. X5R 10V; verify effective capacitance under DC bias
- [ ] **220uF 10V — fit 1; buy 5.** C11. Package: Capacitor_SMD:CP_Elec_6.3x5.8. Low ESR aluminum/polymer; ripple-current rating >=1A; final exact part depends on sourcing
- [ ] **MPU-6050 — fit 1; buy 1.** U3. Package: Sensor_Motion:InvenSense_QFN-24_4x4mm_P0.5mm. I2C address0x68; use genuine bare chip, orientation must be calibrated in firmware
- [ ] **10R — fit 1; buy 5.** R5. Package: Resistor_SMD:R_0402_1005Metric. 1%, 0402
- [ ] **10nF — fit 1; buy 5.** C14. Package: Capacitor_SMD:C_0402_1005Metric. X7R, 10V; use specified voltage where marked
- [ ] **2.2nF 50V — fit 1; buy 5.** C16. Package: Capacitor_SMD:C_0402_1005Metric. X7R 50V +/-10%; charge pump capacitor
- [ ] **4.7k — fit 4; buy 6.** R6, R7, R8, R9. Package: Resistor_SMD:R_0402_1005Metric. 1%, 0402
- [ ] **OV2640 flex / FH12-24S-0.5SH(55) — fit 1; buy 1.** J3. Package: Connector_FFC-FPC:Hirose_FH12-24S-0.5SH_1x24-1MP_P0.50mm_Horizontal. ONLY pin-compatible 24pin0.5mm OV2640 flex; bottom-contact connector, confirm flex contact side/length before purchase
- [ ] **TLV70028DDCR — fit 1; buy 1.** U4. Package: Package_TO_SOT_SMD:SOT-23-5. 2.8V analog camera rail,200mA
- [ ] **TLV70012DDCR — fit 1; buy 1.** U5. Package: Package_TO_SOT_SMD:SOT-23-5. 1.2V core camera rail,200mA
- [ ] **33R — fit 1; buy 5.** R12. Package: Resistor_SMD:R_0402_1005Metric. Source series damping; tune with scope
- [ ] **AO3400A — fit 4; buy 5.** Q1, Q2, Q3, Q4. Package: Package_TO_SOT_SMD:SOT-23. SOT23 G1/S2/D3; verify stall current and heating with actual prop
- [ ] **100R — fit 4; buy 6.** R13, R14, R15, R16. Package: Resistor_SMD:R_0402_1005Metric. 1%, 0402
- [ ] **SS34 — fit 4; buy 5.** D1, D2, D3, D4. Package: Diode_SMD:D_SMA. 3A40V Schottky flyback; cathode pad1 to VBAT
- [ ] **100nF 16V motor-mounted — fit 4; buy 6.** C101, C102, C103, C104. Package: off-board radial ceramic at motor terminals. Solder directly across motor terminals; included in BOM, off-board

## Additional original-board items

- [ ] 1 × OV2640 flex camera assembly with the exact AI-Thinker v1.6 24-pin pinout and compatible contact side; the camera connector above does not include the sensor/lens assembly.
- [ ] 1 × USB-UART adapter using 3.3 V logic, plus programming wires; use the programming instructions in README.md.
- [ ] Custom four-layer PCB and appropriate stencil/assembly service or reflow tools; the bare QFN packages are not intended for direct perfboard installation.
- [ ] Four motors, battery and suitable connector, charger, frame, matched propellers, wiring and mechanical supplies: see the shared-hardware section of prototype/shopping-list.md.

Original BOM.csv remains the per-reference source of truth. Electrical passives must meet the voltage/dielectric notes; CPOUT is 2.2 nF / 50 V. Manufacturer part numbers for generic resistors/capacitors and C11 remain sourcing choices.

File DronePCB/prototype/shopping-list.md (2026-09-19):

# Shopping list — one perfboard quadcopter controller

Buy the quantities below minus items you already own. “Buy” includes a few inexpensive spares; “fit” is the number used. **This replaces the bare-chip electronics shopping list for the prototype. Do not buy both sets for one build.** The original SMD version has a separate grouped list in ../shopping-list-original-PCB.md.

## Modules and motor switches

- [ ] **1 × Freenove FNK0085 ESP32-S3-WROOM camera board**, N8R8 or N16R8, with matching OV2640 camera and headers. Buy the board/camera bundle, without the large terminal expansion shield. No separate programmer, bare ESP32, flash, camera FPC connector or camera LDO is required. [Manufacturer](https://github.com/Freenove/Freenove_ESP32_S3_WROOM_Board).
- [ ] **1 × Adafruit MPU-6050 breakout with header pins**, fitted as U2. Supply VIN from 3.3 V. A GY-521 can be cheaper/local, but its regulator and pullups must be checked before substitution; see README. [Documented breakout](https://learn.adafruit.com/mpu6050-6-dof-accelerometer-and-gyro/pinouts).
- [ ] **1 × Pololu U3V40F5 fixed 5 V boost module**, U3. An alternative must deliver 5 V / 1 A from 3.0 V input, not merely advertise a 1 A or 2 A switch rating. [Reference module](https://www.pololu.com/product/4012).
- [ ] **8 × AO3400A MOSFETs**, fit 4 as Q1–Q4; reuse your existing parts if genuine and undamaged. SOT-23, gate pin1/source pin2/drain pin3. Buy pre-soldered adapters if you do not want to solder SMD.
- [ ] **4 × SOT-23-to-2.54 mm adapters**, preferably buy 6. Pick adapters with useful drain/source copper and short current paths. Generic tiny signal adapters are not automatically rated for 1.74 A motor operation; reinforce/test as described in README. If buying preassembled AO3400A adapters, the MOSFETs above are already included.
- [ ] **6 × 1N5822 axial Schottky diodes, 3 A / 40 V**, fit 4 as D1–D4. Banded end goes to battery positive. Do not substitute a 1N400x general-purpose rectifier or 1 A 1N5819 without redesign.

## Through-hole resistors — 1/4 W, preferably 1%

- [ ] **100 Ω: fit 4, buy 10** — R1–R4, series gate resistors.
- [ ] **10 kΩ: fit 4, buy 10** — R5–R8, gate-to-source pulldowns.
- [ ] **4.7 kΩ: fit 2, buy 5** — R9–R10, IMU I2C pullups to 3.3 V.
- [ ] **100 kΩ, 1%: fit 2, buy 5** — R11–R12, battery divider.

## Through-hole capacitors

- [ ] **100 nF (104), ceramic, X7R, 16 V or higher: fit 7, buy 10** — C1–C4 directly on motors; C12 at ESP 5 V; C13 on battery ADC; C14 at IMU supply. Radial leads, preferably 2.5 or 5 mm pitch.
- [ ] **10 µF, 10 V or higher, radial electrolytic: fit 5, buy 10** — C5–C8 driver supply bypass and C15 IMU bulk bypass. Choose compact parts; low ESR preferred. Match polarity.
- [ ] **47 µF, 10 V or higher, radial low-ESR electrolytic: fit 1, buy 2** — C10 at boost VIN.
- [ ] **100 µF, 10 V or higher, radial low-ESR electrolytic: fit 1, buy 2** — C11 at ESP 5 V input.
- [ ] **470 µF, 10 V, radial low-ESR electrolytic: fit 1, buy 2** — C9 at battery distribution. Choose a part with a published ripple-current rating of at least 1 A; verify temperature and rail ripple on the assembled prototype. Avoid large high-voltage substitutes that add unnecessary mass.

## Shared drone hardware — reuse what you have

- [ ] **4 × 8520 brushed coreless motors, nominal 3.7 V**, preferably a matched set of two CW and two CCW motors where the manufacturer specifies direction. Your stated running current is 1.74 A per motor; obtain or measure startup/stall current. No separate brushless ESCs are used.
- [ ] **1 × 1S 3.7 V 700 mAh 20C LiPo**, as already specified. Its label implies 14 A; verify real voltage sag and connector rating. A 2S battery is incompatible.
- [ ] **1 matching battery connector pair with short leads**, e.g. genuine XT30 if weight allows, or another connector with documented rating for the measured combined load. Do not assume a small JST-PH/Dupont connector can carry the four motors. If the pack already has a suitably rated connector, buy only its mating half. Confirm polarity with a meter.
- [ ] **1 × 1S LiPo charger**, correct 4.2 V termination and charge current permitted by your battery maker; 300–500 mA is a conservative starting choice only if allowed by the pack. Charging is off-board with the battery disconnected from the drone.
- [ ] **1 lightweight frame for four 8.5 mm diameter motors**, with room for the battery and perfboard. Check motor length, mounting method and total mass.
- [ ] **2 CW + 2 CCW matched propellers**, plus a spare set. Diameter, pitch and shaft fit must match the actual 8520 motors and frame; do not choose from “8520” alone.
- [ ] **Battery strap, insulating pad, wire strain relief and lightweight fasteners**, one small set. Use a secure IMU mount and check vibration; avoid a floppy module mounting.
- [ ] **Existing phone/computer for Wi-Fi commands and video**, plus compatible control firmware/software. No separate radio receiver is included in this Wi-Fi architecture.

## Perfboard and wiring

- [ ] **1 × 2.54 mm isolated-pad solderable perfboard**, about 60 × 80 mm starting size, thin double-sided plated board preferred. Trim after test fitting. This is برد سوراخ‌دار, not a solderless breadboard.
- [ ] **2 × 1×20 female socket strips, 2.54 mm**, for the selected 40-pin ESP board on the bench; check the actual header count/row spacing before soldering. Direct-solder or secure the connections for flight.
- [ ] **2 × 1×40 breakaway male header strips** and **1 × 1×40 female strip** to cut for sensor, regulator and adapters. Omit lengths already supplied/soldered on modules. High-current motor paths should use direct wires, not these sockets.
- [ ] **20 AWG flexible silicone wire, red/black: about 0.5 m of each** for short main battery/distribution wiring. Use 18 AWG if the run is longer or measured current demands it.
- [ ] **24 AWG flexible silicone wire: about 1 m total** for short motor branches; reuse adequate original motor leads.
- [ ] **28–30 AWG insulated signal wire: about 2 m total**, assorted colours; keep actual runs short.
- [ ] **Tinned copper bus wire around 0.8 mm diameter: about 0.5 m**, for short soldered power distribution, with insulation where it crosses other connections. Final current capability depends on length and temperature.
- [ ] **Heat-shrink assortment, solder, flux and insulation tape**, small quantities.
- [ ] **USB data cable matching the board** for programming. Disconnect the battery while using normal USB power.

## Bench equipment — borrow/reuse if available

- [ ] Soldering iron, cutters, tweezers and magnifier. An assembled AO3400A adapter avoids hand-soldering the SOT-23 package.
- [ ] Multimeter and current-limited bench supply. Test one motor at a time before whole-system load tests; supply and current measurement must cover the measured current.
- [ ] Scale with roughly 0.1 g resolution and a restrained thrust-test arrangement to establish flight weight/thrust margin.
- [ ] Oscilloscope access is useful for supply dips, PWM and I2C verification; it is test equipment, not an onboard component.

No flight duration, maximum lift or total price is promised: exact seller parts, propellers, available thrust and assembled mass are still unknown. Manufacturer links identify the reference parts; local availability and prices have not been checked.

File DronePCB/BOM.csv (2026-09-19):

Reference | Value_or_MPN | Footprint | On_PCB | Notes
U1 | ESP32-S3-MINI-1-N4R2 | RF_Module:ESP32-S2-MINI-1 | True | 4MB flash / 2MB PSRAM; module antenna extends beyond top board edge
C1 | 10uF | Capacitor_SMD:C_0603_1608Metric | True | X7R, 10V; use specified voltage where marked
C2 | 100nF | Capacitor_SMD:C_0402_1005Metric | True | X7R, 10V; use specified voltage where marked
R1 | 10k | Resistor_SMD:R_0402_1005Metric | True | 1%, 0402
C3 | 1uF | Capacitor_SMD:C_0402_1005Metric | True | X7R, 10V; use specified voltage where marked
R2 | 10k | Resistor_SMD:R_0402_1005Metric | True | 1%, 0402
J1 | 3.3V UART programmer pads | Drone:Programming_6 | True | External programmer: 3.3V logic only; pin2 reference only with battery attached
R3 | 100k | Resistor_SMD:R_0402_1005Metric | True | 1%, 0402
R4 | 100k | Resistor_SMD:R_0402_1005Metric | True | 1%, 0402
C4 | 100nF | Capacitor_SMD:C_0402_1005Metric | True | X7R, 10V; use specified voltage where marked
U2 | TPS63021DSJR | Drone:TI_DSJ14_TPS63021 | True | Fixed3.3V; power-save mode; 1A electronics design target at VBAT>=3.0V subject to bench testing
L1 | 1.5uH XFL4020-152MEC | Drone:XFL4020 | True | Coilcraft reference inductor; confirm exact suffix and DCR at sourcing
C5 | 10uF | Capacitor_SMD:C_0603_1608Metric | True | X7R, 10V; use specified voltage where marked
C6 | 10uF | Capacitor_SMD:C_0603_1608Metric | True | X7R, 10V; use specified voltage where marked
C7 | 100nF | Capacitor_SMD:C_0402_1005Metric | True | X7R, 10V; use specified voltage where marked
C8 | 22uF | Capacitor_SMD:C_0805_2012Metric | True | X5R 10V; verify effective capacitance under DC bias
C9 | 22uF | Capacitor_SMD:C_0805_2012Metric | True | X5R 10V; verify effective capacitance under DC bias
C10 | 22uF | Capacitor_SMD:C_0805_2012Metric | True | X5R 10V; verify effective capacitance under DC bias
J2 | 1S LiPo 700mAh 20C | Drone:Battery_2 | True | Direct solder pads; no charger or reverse-polarity protection; disconnect battery when unused
C11 | 220uF 10V | Capacitor_SMD:CP_Elec_6.3x5.8 | True | Low ESR aluminum/polymer; ripple-current rating >=1A; final exact part depends on sourcing
U3 | MPU-6050 | Sensor_Motion:InvenSense_QFN-24_4x4mm_P0.5mm | True | I2C address0x68; use genuine bare chip, orientation must be calibrated in firmware
R5 | 10R | Resistor_SMD:R_0402_1005Metric | True | 1%, 0402
C12 | 1uF | Capacitor_SMD:C_0402_1005Metric | True | X7R, 10V; use specified voltage where marked
C13 | 100nF | Capacitor_SMD:C_0402_1005Metric | True | X7R, 10V; use specified voltage where marked
C14 | 10nF | Capacitor_SMD:C_0402_1005Metric | True | X7R, 10V; use specified voltage where marked
C15 | 100nF | Capacitor_SMD:C_0402_1005Metric | True | X7R, 10V; use specified voltage where marked
C16 | 2.2nF 50V | Capacitor_SMD:C_0402_1005Metric | True | X7R 50V +/-10%; charge pump capacitor
R6 | 4.7k | Resistor_SMD:R_0402_1005Metric | True | 1%, 0402
R7 | 4.7k | Resistor_SMD:R_0402_1005Metric | True | 1%, 0402
J3 | OV2640 flex / FH12-24S-0.5SH(55) | Connector_FFC-FPC:Hirose_FH12-24S-0.5SH_1x24-1MP_P0.50mm_Horizontal | True | ONLY pin-compatible 24pin0.5mm OV2640 flex; bottom-contact connector, confirm flex contact side/length before purchase
U4 | TLV70028DDCR | Package_TO_SOT_SMD:SOT-23-5 | True | 2.8V analog camera rail,200mA
U5 | TLV70012DDCR | Package_TO_SOT_SMD:SOT-23-5 | True | 1.2V core camera rail,200mA
C17 | 1uF | Capacitor_SMD:C_0402_1005Metric | True | X7R, 10V; use specified voltage where marked
C18 | 1uF | Capacitor_SMD:C_0402_1005Metric | True | X7R, 10V; use specified voltage where marked
C19 | 1uF | Capacitor_SMD:C_0402_1005Metric | True | X7R, 10V; use specified voltage where marked
C20 | 1uF | Capacitor_SMD:C_0402_1005Metric | True | X7R, 10V; use specified voltage where marked
C21 | 100nF | Capacitor_SMD:C_0402_1005Metric | True | X7R, 10V; use specified voltage where marked
C22 | 100nF | Capacitor_SMD:C_0402_1005Metric | True | X7R, 10V; use specified voltage where marked
C23 | 100nF | Capacitor_SMD:C_0402_1005Metric | True | X7R, 10V; use specified voltage where marked
R8 | 4.7k | Resistor_SMD:R_0402_1005Metric | True | 1%, 0402
R9 | 4.7k | Resistor_SMD:R_0402_1005Metric | True | 1%, 0402
R10 | 10k | Resistor_SMD:R_0402_1005Metric | True | 1%, 0402
C24 | 100nF | Capacitor_SMD:C_0402_1005Metric | True | X7R, 10V; use specified voltage where marked
R11 | 10k | Resistor_SMD:R_0402_1005Metric | True | 1%, 0402
R12 | 33R | Resistor_SMD:R_0402_1005Metric | True | Source series damping; tune with scope
Q1 | AO3400A | Package_TO_SOT_SMD:SOT-23 | True | SOT23 G1/S2/D3; verify stall current and heating with actual prop
R13 | 100R | Resistor_SMD:R_0402_1005Metric | True | 1%, 0402
R17 | 10k | Resistor_SMD:R_0402_1005Metric | True | 1%, 0402
D1 | SS34 | Diode_SMD:D_SMA | True | 3A40V Schottky flyback; cathode pad1 to VBAT
J4 | 8520 motor 1 | Drone:Motor_2 | True | Direct motor wire solder pads; motor body not on PCB
C25 | 10uF | Capacitor_SMD:C_0603_1608Metric | True | X7R, 10V; use specified voltage where marked
C101 | 100nF 16V motor-mounted |  | False | Solder directly across motor terminals; included in BOM, off-board
Q2 | AO3400A | Package_TO_SOT_SMD:SOT-23 | True | SOT23 G1/S2/D3; verify stall current and heating with actual prop
R14 | 100R | Resistor_SMD:R_0402_1005Metric | True | 1%, 0402
R18 | 10k | Resistor_SMD:R_0402_1005Metric | True | 1%, 0402
D2 | SS34 | Diode_SMD:D_SMA | True | 3A40V Schottky flyback; cathode pad1 to VBAT
J5 | 8520 motor 2 | Drone:Motor_2 | True | Direct motor wire solder pads; motor body not on PCB
C26 | 10uF | Capacitor_SMD:C_0603_1608Metric | True | X7R, 10V; use specified voltage where marked
C102 | 100nF 16V motor-mounted |  | False | Solder directly across motor terminals; included in BOM, off-board
Q3 | AO3400A | Package_TO_SOT_SMD:SOT-23 | True | SOT23 G1/S2/D3; verify stall current and heating with actual prop
R15 | 100R | Resistor_SMD:R_0402_1005Metric | True | 1%, 0402
R19 | 10k | Resistor_SMD:R_0402_1005Metric | True | 1%, 0402
D3 | SS34 | Diode_SMD:D_SMA | True | 3A40V Schottky flyback; cathode pad1 to VBAT
J6 | 8520 motor 3 | Drone:Motor_2 | True | Direct motor wire solder pads; motor body not on PCB
C27 | 10uF | Capacitor_SMD:C_0603_1608Metric | True | X7R, 10V; use specified voltage where marked
C103 | 100nF 16V motor-mounted |  | False | Solder directly across motor terminals; included in BOM, off-board
Q4 | AO3400A | Package_TO_SOT_SMD:SOT-23 | True | SOT23 G1/S2/D3; verify stall current and heating with actual prop
R16 | 100R | Resistor_SMD:R_0402_1005Metric | True | 1%, 0402
R20 | 10k | Resistor_SMD:R_0402_1005Metric | True | 1%, 0402
D4 | SS34 | Diode_SMD:D_SMA | True | 3A40V Schottky flyback; cathode pad1 to VBAT
J7 | 8520 motor 4 | Drone:Motor_2 | True | Direct motor wire solder pads; motor body not on PCB
C28 | 10uF | Capacitor_SMD:C_0603_1608Metric | True | X7R, 10V; use specified voltage where marked
C104 | 100nF 16V motor-mounted |  | False | Solder directly across motor terminals; included in BOM, off-board

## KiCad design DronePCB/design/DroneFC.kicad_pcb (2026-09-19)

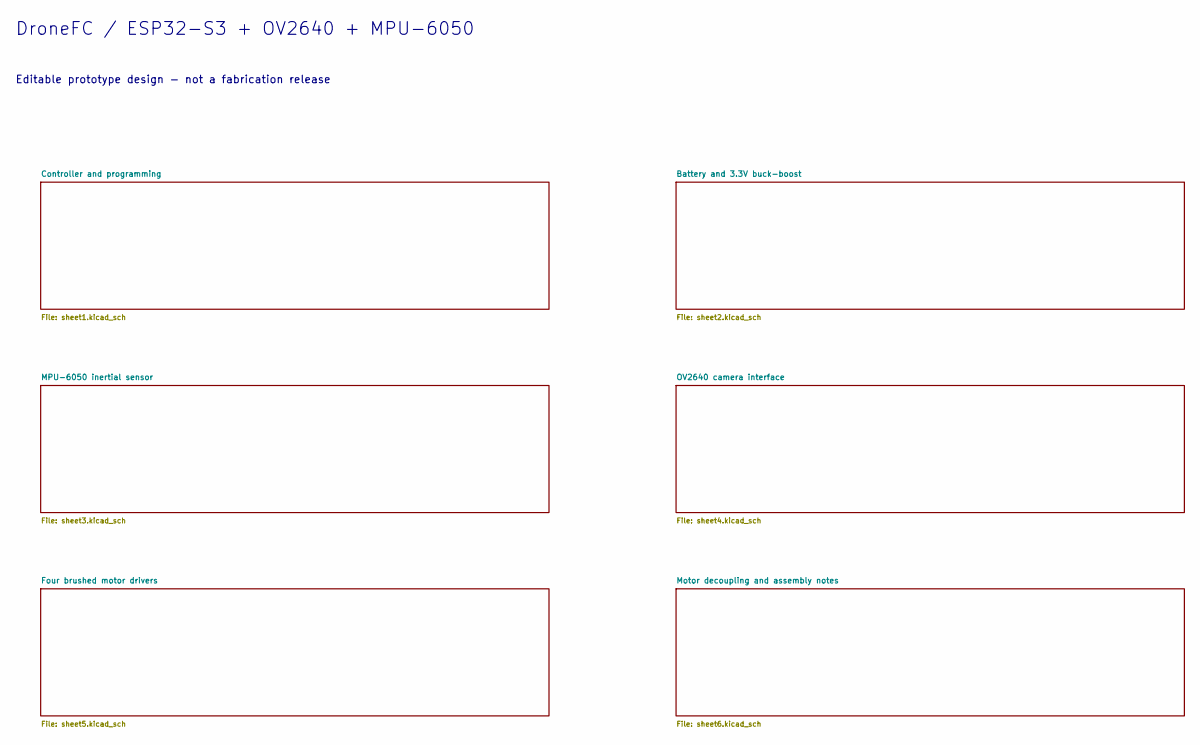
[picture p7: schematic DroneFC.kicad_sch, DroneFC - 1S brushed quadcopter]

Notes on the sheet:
DroneFC / ESP32-S3 + OV2640 + MPU-6050
Editable prototype design - not a fabrication release

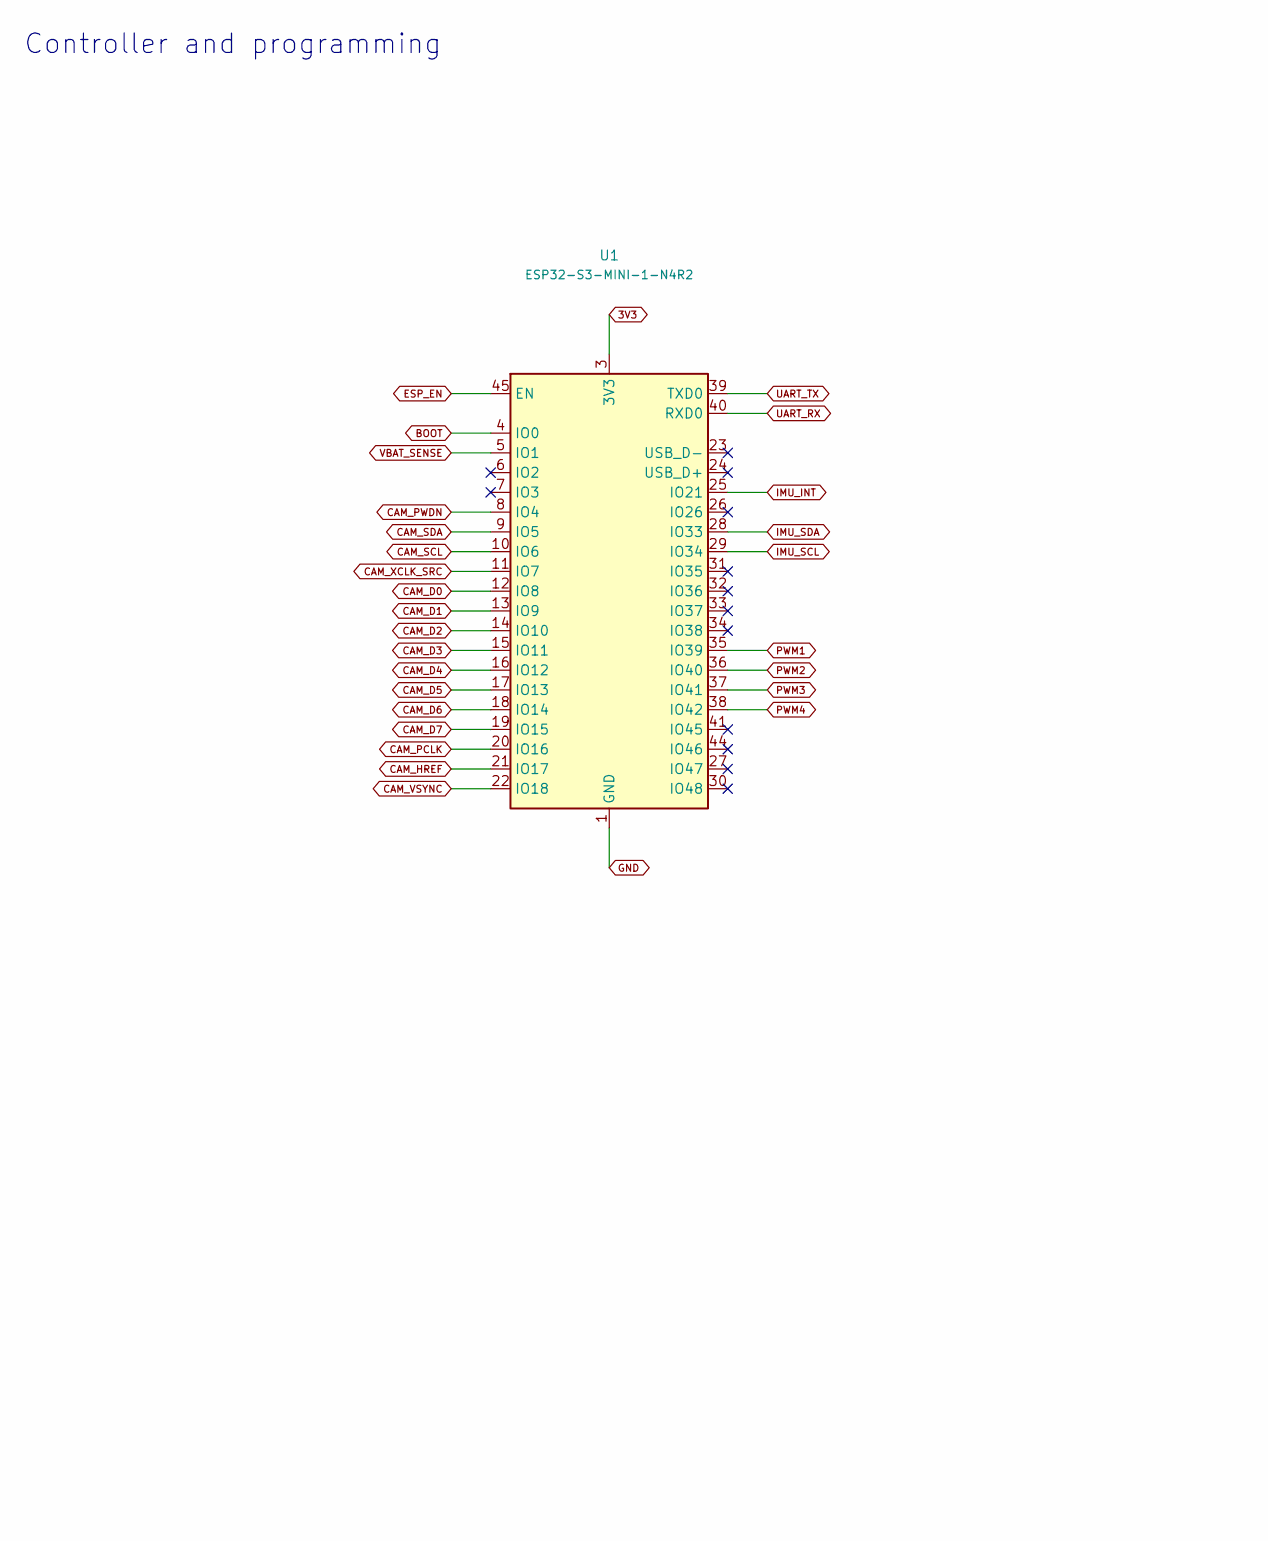
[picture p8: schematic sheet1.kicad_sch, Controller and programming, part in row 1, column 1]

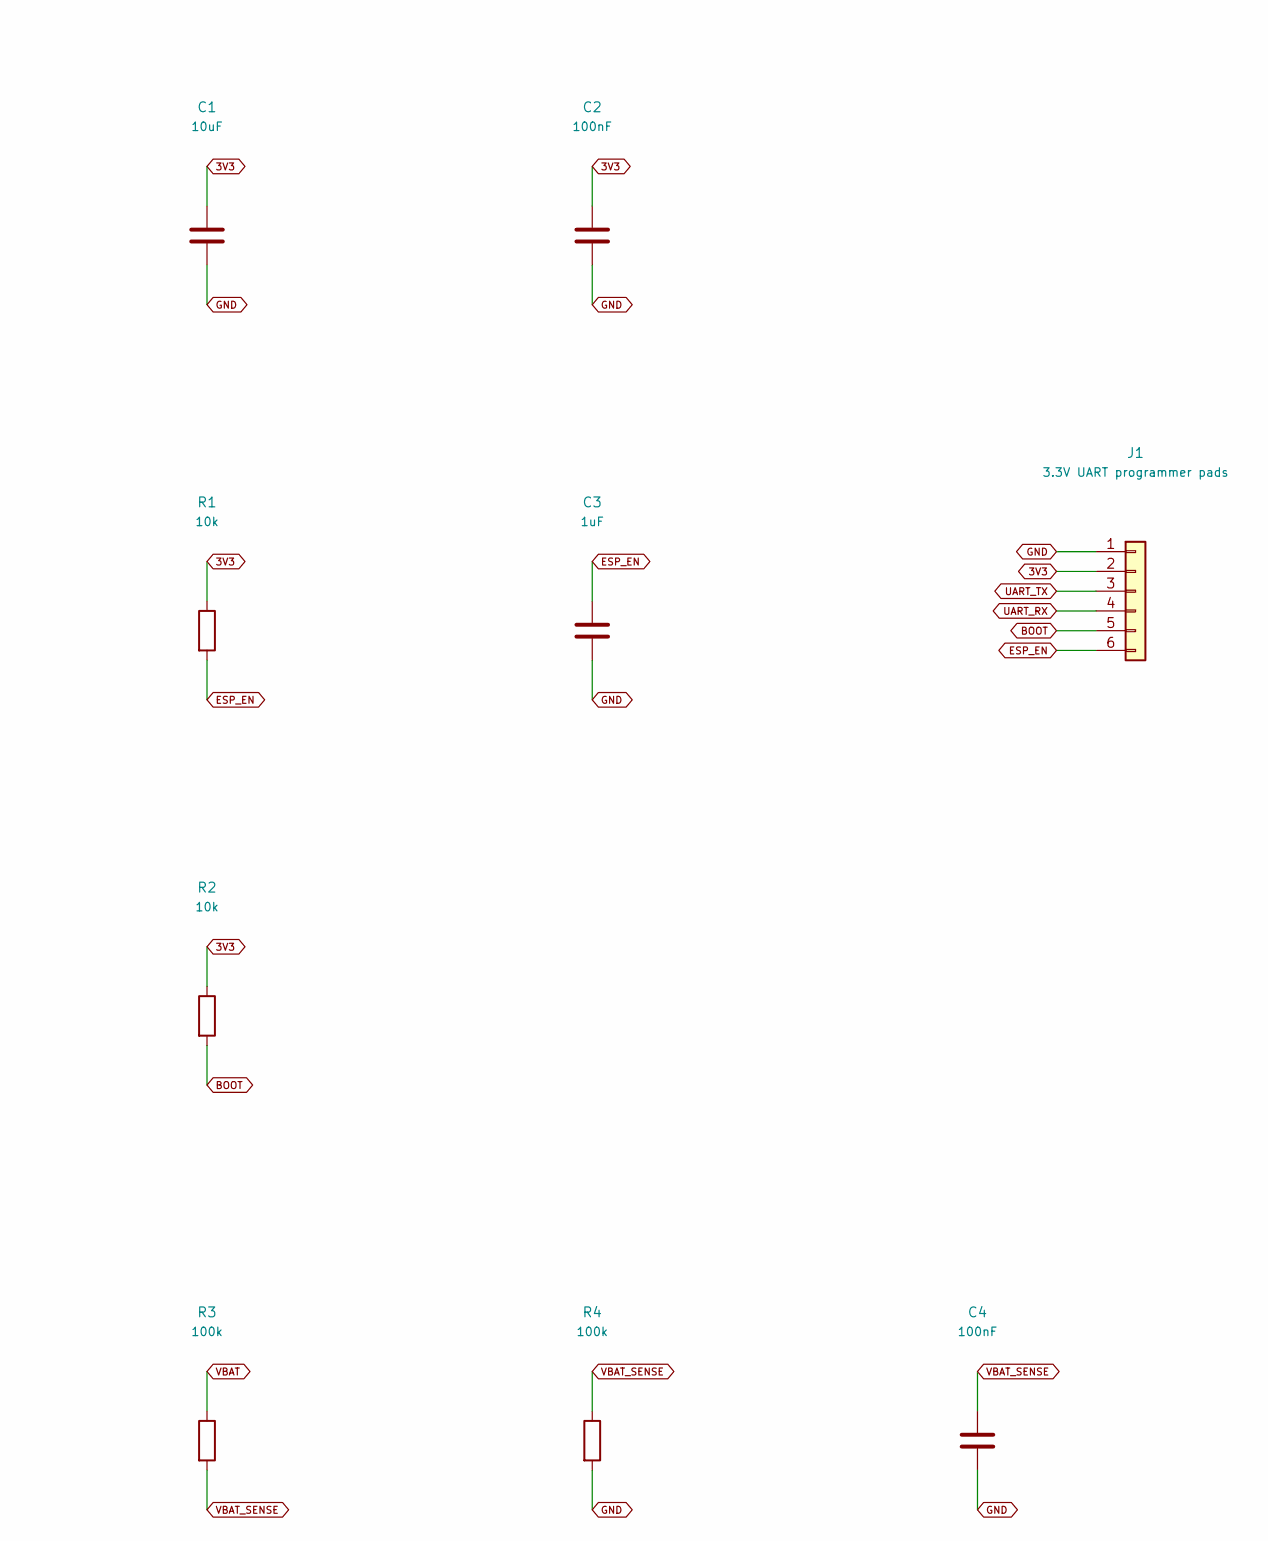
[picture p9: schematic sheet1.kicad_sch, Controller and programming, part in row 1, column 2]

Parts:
C1: 10uF; C_0603_1608Metric
C2, C4: 100nF; C_0402_1005Metric
C3: 1uF; C_0402_1005Metric
J1: 3.3V UART programmer pads; Programming_6
R1, R2: 10k; R_0402_1005Metric
R3, R4: 100k; R_0402_1005Metric
U1: ESP32-S3-MINI-1-N4R2; ESP32-S2-MINI-1

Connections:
3V3: C1.1, C2.1, J1.2, R1.1, R2.1, U1.3 (3V3); also elsewhere on the board
BOOT: J1.5, R2.2, U1.4 (IO0)
CAM_D0: U1.12 (IO8); also elsewhere on the board
CAM_D1: U1.13 (IO9); also elsewhere on the board
CAM_D2: U1.14 (IO10); also elsewhere on the board
CAM_D3: U1.15 (IO11); also elsewhere on the board
CAM_D4: U1.16 (IO12); also elsewhere on the board
CAM_D5: U1.17 (IO13); also elsewhere on the board
CAM_D6: U1.18 (IO14); also elsewhere on the board
CAM_D7: U1.19 (IO15); also elsewhere on the board
CAM_HREF: U1.21 (IO17); also elsewhere on the board
CAM_PCLK: U1.20 (IO16); also elsewhere on the board
CAM_PWDN: U1.8 (IO4); also elsewhere on the board
CAM_SCL: U1.10 (IO6); also elsewhere on the board
CAM_SDA: U1.9 (IO5); also elsewhere on the board
CAM_VSYNC: U1.22 (IO18); also elsewhere on the board
CAM_XCLK_SRC: U1.11 (IO7); also elsewhere on the board
ESP_EN: C3.1, J1.6, R1.2, U1.45 (EN)
GND: C1.2, C2.2, C3.2, C4.2, J1.1, R4.2, U1.1 (GND), U1.2 (GND), U1.42 (GND), U1.43 (GND), U1.46 (GND), U1.47 (GND), U1.48 (GND), U1.49 (GND), U1.50 (GND), U1.51 (GND), U1.52 (GND), U1.53 (GND), U1.54 (GND), U1.55 (GND), U1.56 (GND), U1.57 (GND), U1.58 (GND), U1.59 (GND), U1.60 (GND), U1.61 (GND), U1.62 (GND), U1.63 (GND), U1.64 (GND), U1.65 (GND); also elsewhere on the board
IMU_INT: U1.25 (IO21); also elsewhere on the board
IMU_SCL: U1.29 (IO34); also elsewhere on the board
IMU_SDA: U1.28 (IO33); also elsewhere on the board
PWM1: U1.35 (IO39); also elsewhere on the board
PWM2: U1.36 (IO40); also elsewhere on the board
PWM3: U1.37 (IO41); also elsewhere on the board
PWM4: U1.38 (IO42); also elsewhere on the board
UART_RX: J1.4, U1.40 (RXD0)
UART_TX: J1.3, U1.39 (TXD0)
VBAT: R3.1; also elsewhere on the board
VBAT_SENSE: C4.1, R3.2, R4.1, U1.5 (IO1)

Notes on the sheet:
Controller and programming

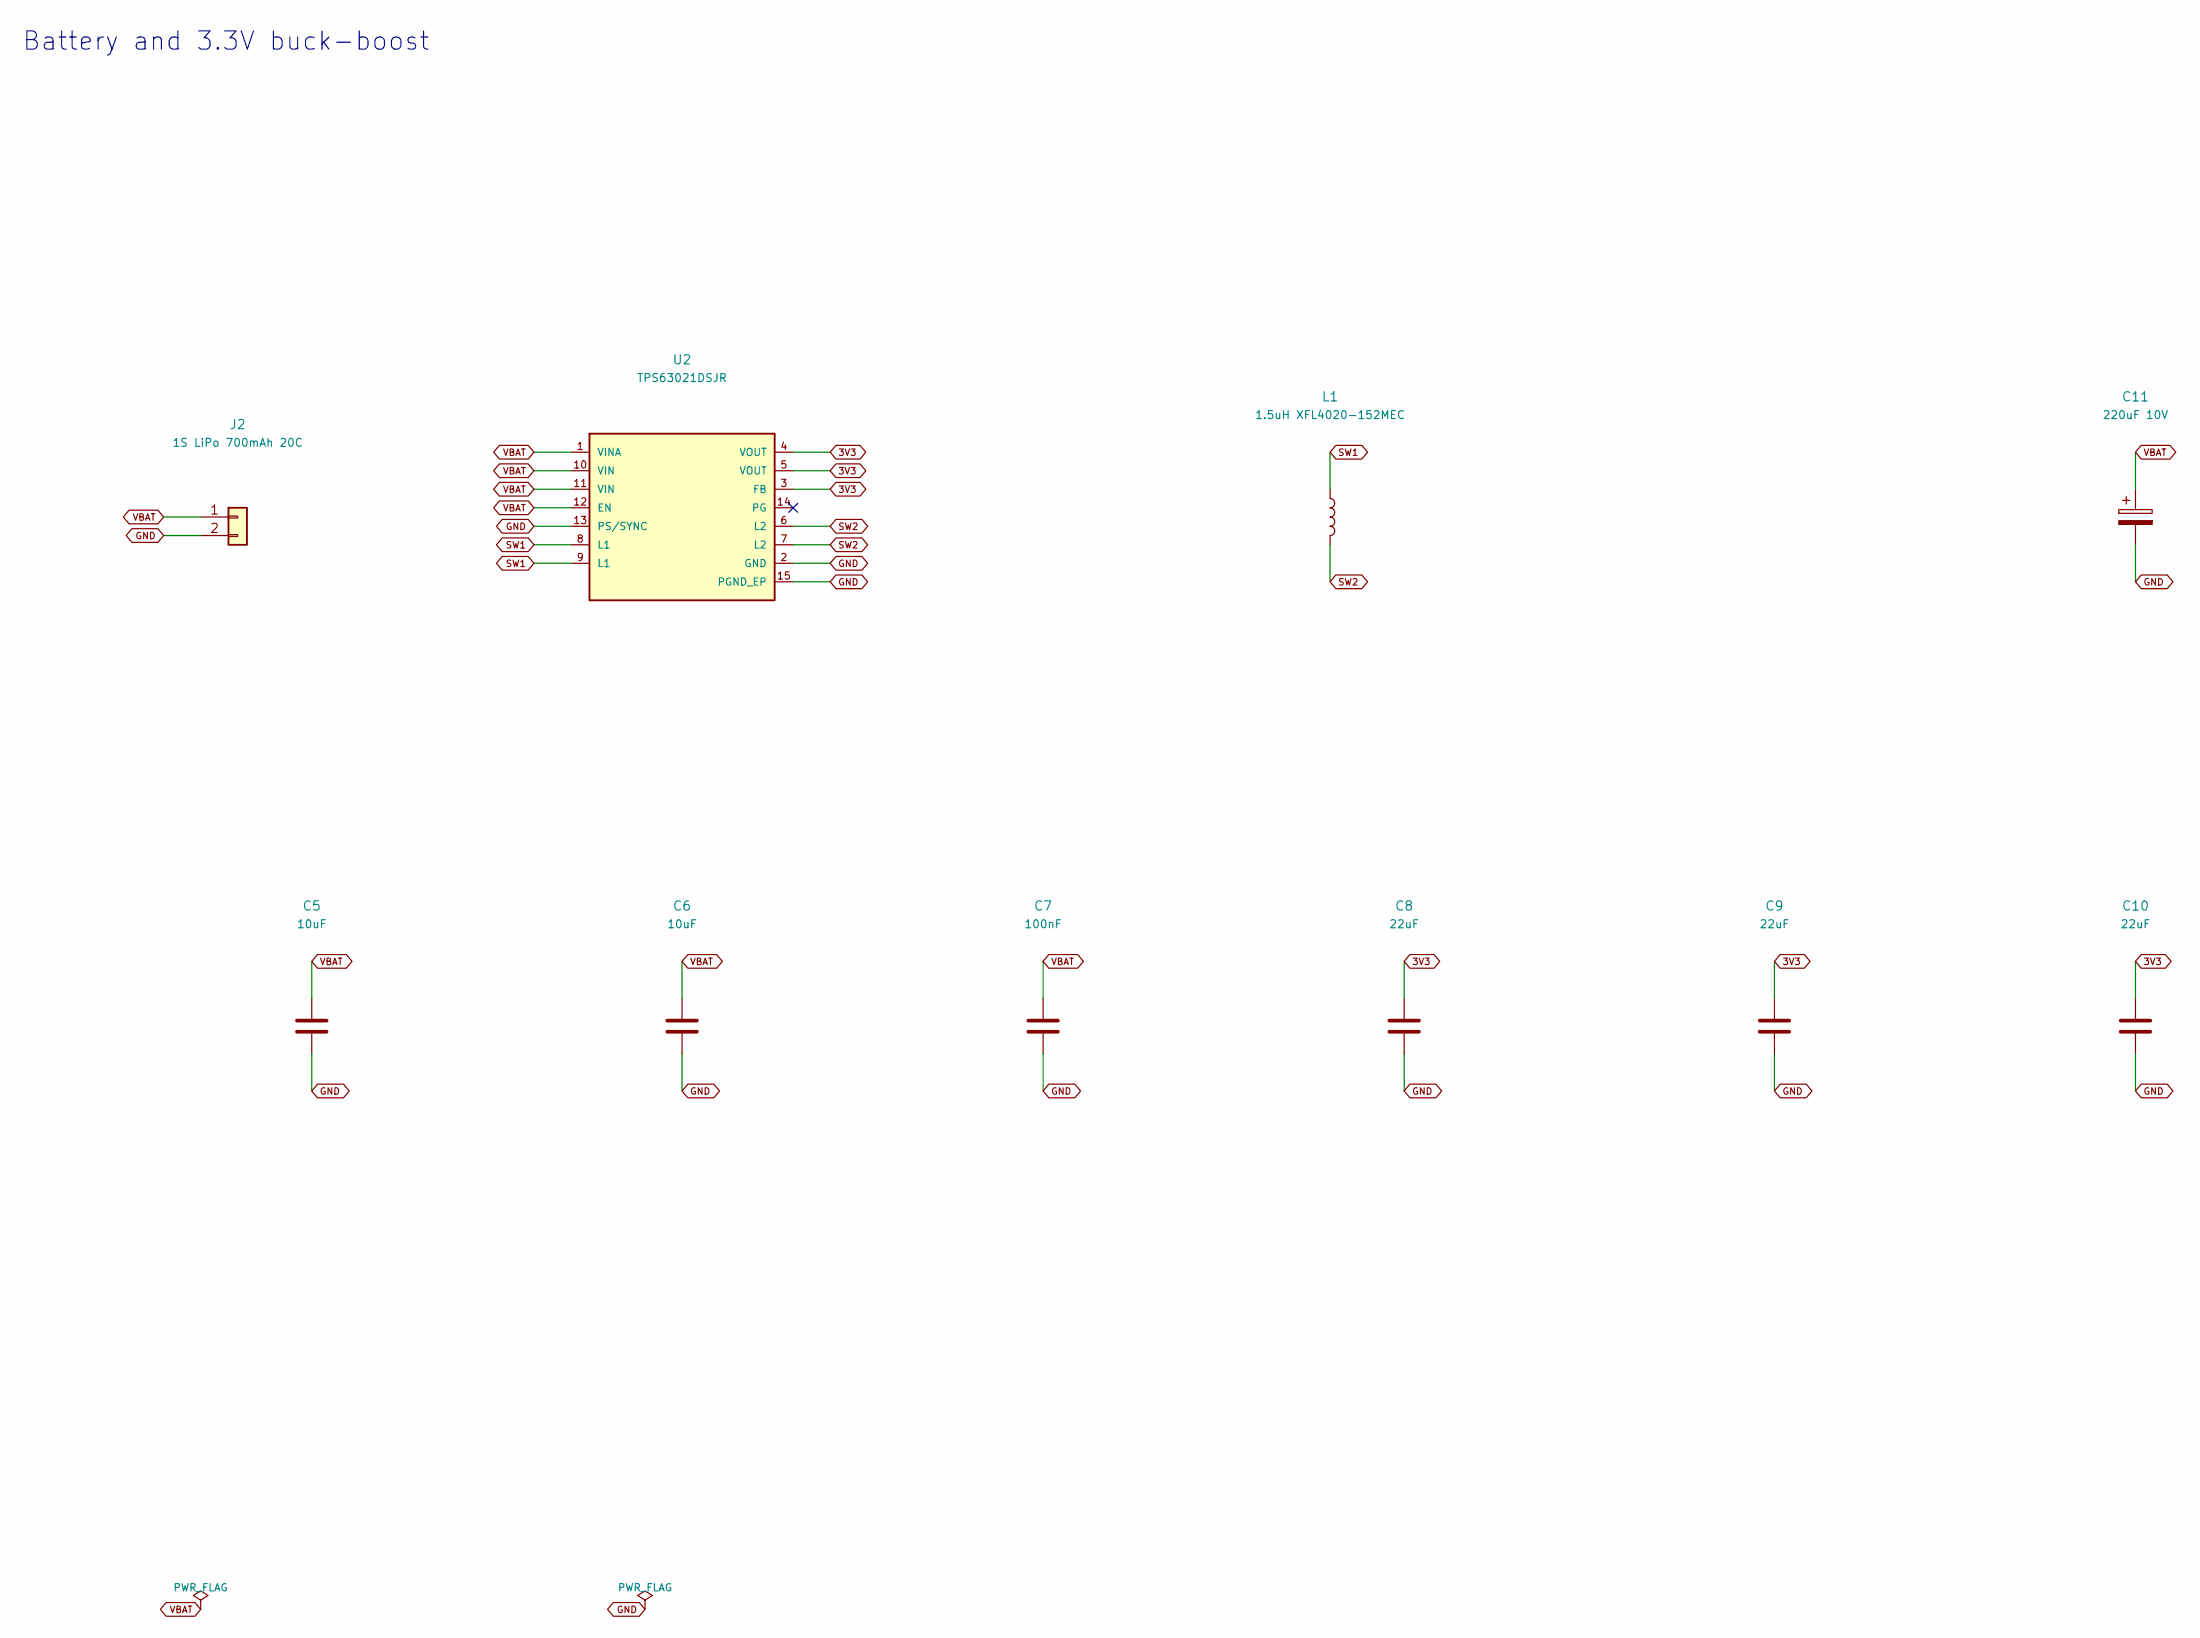
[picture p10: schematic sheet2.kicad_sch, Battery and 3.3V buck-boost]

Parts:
C5, C6: 10uF; C_0603_1608Metric
C7: 100nF; C_0402_1005Metric
C8, C9, C10: 22uF; C_0805_2012Metric
C11: 220uF 10V; CP_Elec_6.3x5.8
J2: 1S LiPo 700mAh 20C; Battery_2
L1: 1.5uH XFL4020-152MEC; XFL4020
U2: TPS63021DSJR; TI_DSJ14_TPS63021

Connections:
3V3: C8.1, C9.1, C10.1, U2.3 (FB), U2.4 (VOUT), U2.5 (VOUT); also elsewhere on the board
GND: C5.2, C6.2, C7.2, C8.2, C9.2, C10.2, C11.2, J2.2, U2.2 (GND), U2.13 (PS/SYNC), U2.15 (PGND_EP); also elsewhere on the board
SW1: L1.1, U2.8 (L1), U2.9 (L1)
SW2: L1.2, U2.6 (L2), U2.7 (L2)
VBAT: C5.1, C6.1, C7.1, C11.1, J2.1, U2.1 (VINA), U2.10 (VIN), U2.11 (VIN), U2.12 (EN); also elsewhere on the board

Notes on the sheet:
Battery and 3.3V buck-boost

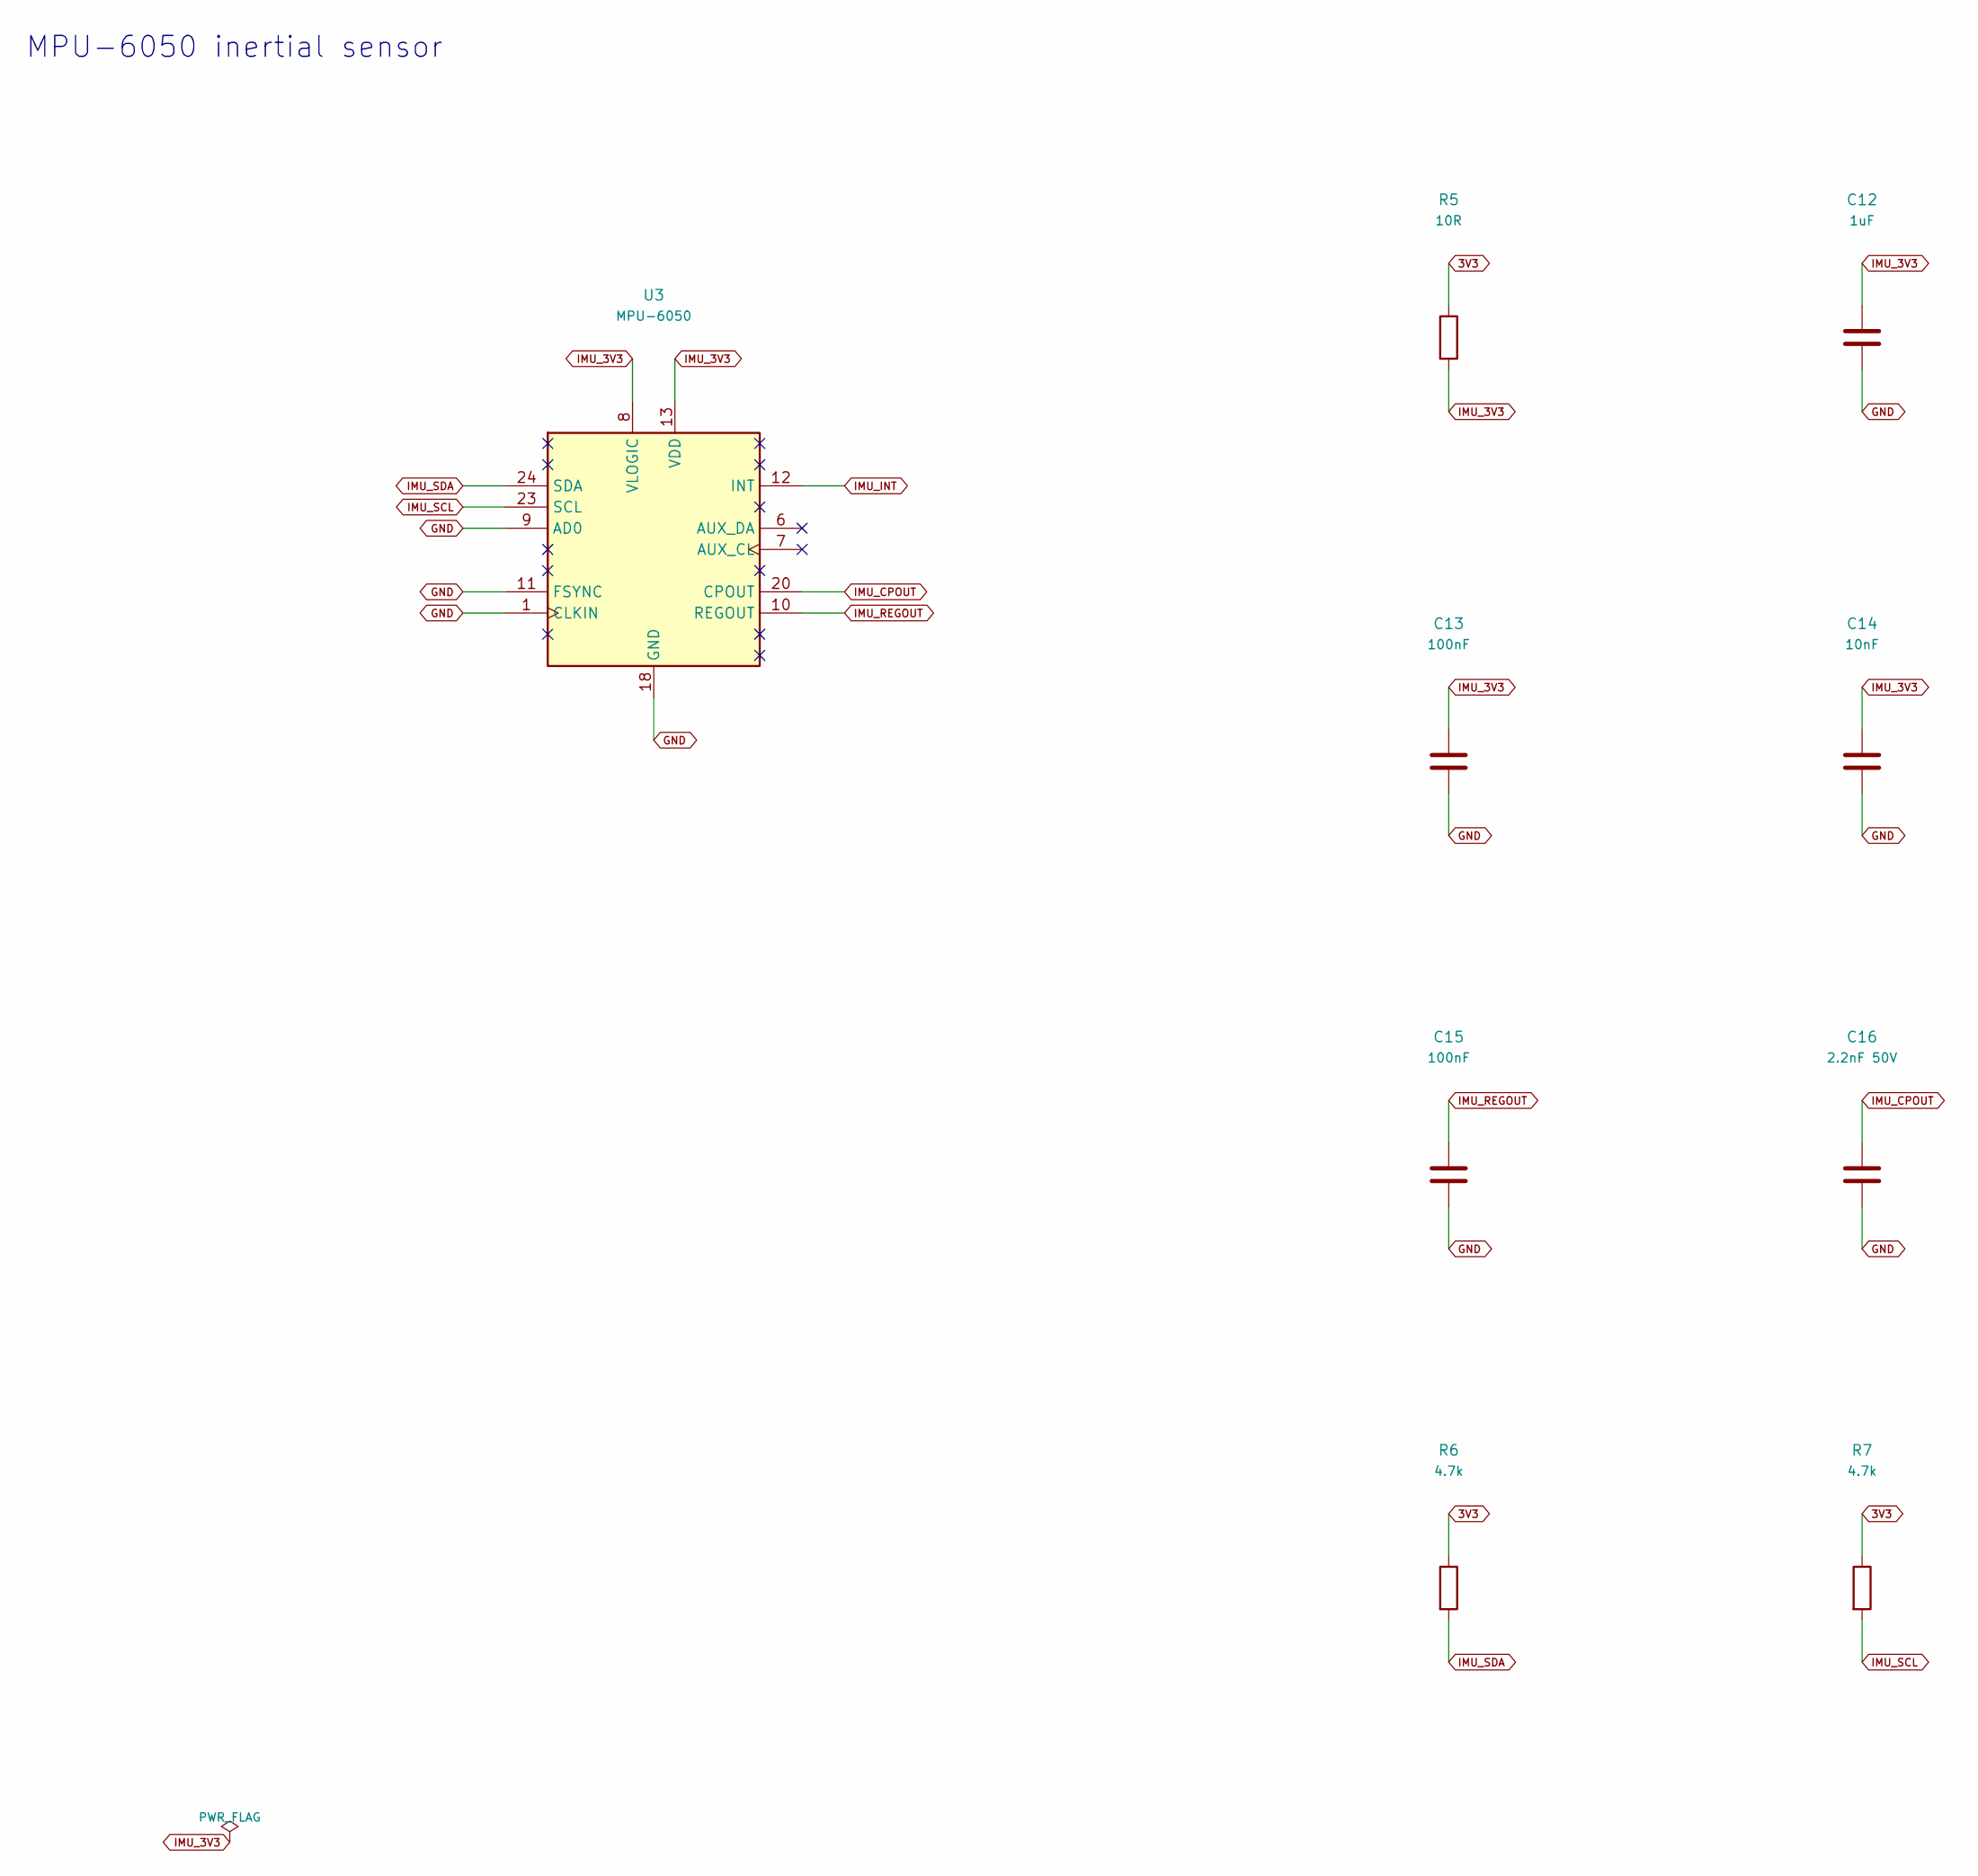
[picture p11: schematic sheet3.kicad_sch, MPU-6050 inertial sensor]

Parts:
C12: 1uF; C_0402_1005Metric
C13, C15: 100nF; C_0402_1005Metric
C14: 10nF; C_0402_1005Metric
C16: 2.2nF 50V; C_0402_1005Metric
R5: 10R; R_0402_1005Metric
R6, R7: 4.7k; R_0402_1005Metric
U3: MPU-6050; InvenSense_QFN-24_4x4mm_P0.5mm

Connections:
3V3: R5.1, R6.1, R7.1; also elsewhere on the board
GND: C12.2, C13.2, C14.2, C15.2, C16.2, U3.1 (CLKIN), U3.9 (AD0), U3.11 (FSYNC), U3.18 (GND); also elsewhere on the board
IMU_3V3: C12.1, C13.1, C14.1, R5.2, U3.8 (VLOGIC), U3.13 (VDD)
IMU_CPOUT: C16.1, U3.20 (CPOUT)
IMU_INT: U3.12 (INT); also elsewhere on the board
IMU_REGOUT: C15.1, U3.10 (REGOUT)
IMU_SCL: R7.2, U3.23 (SCL); also elsewhere on the board
IMU_SDA: R6.2, U3.24 (SDA); also elsewhere on the board

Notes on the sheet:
MPU-6050 inertial sensor

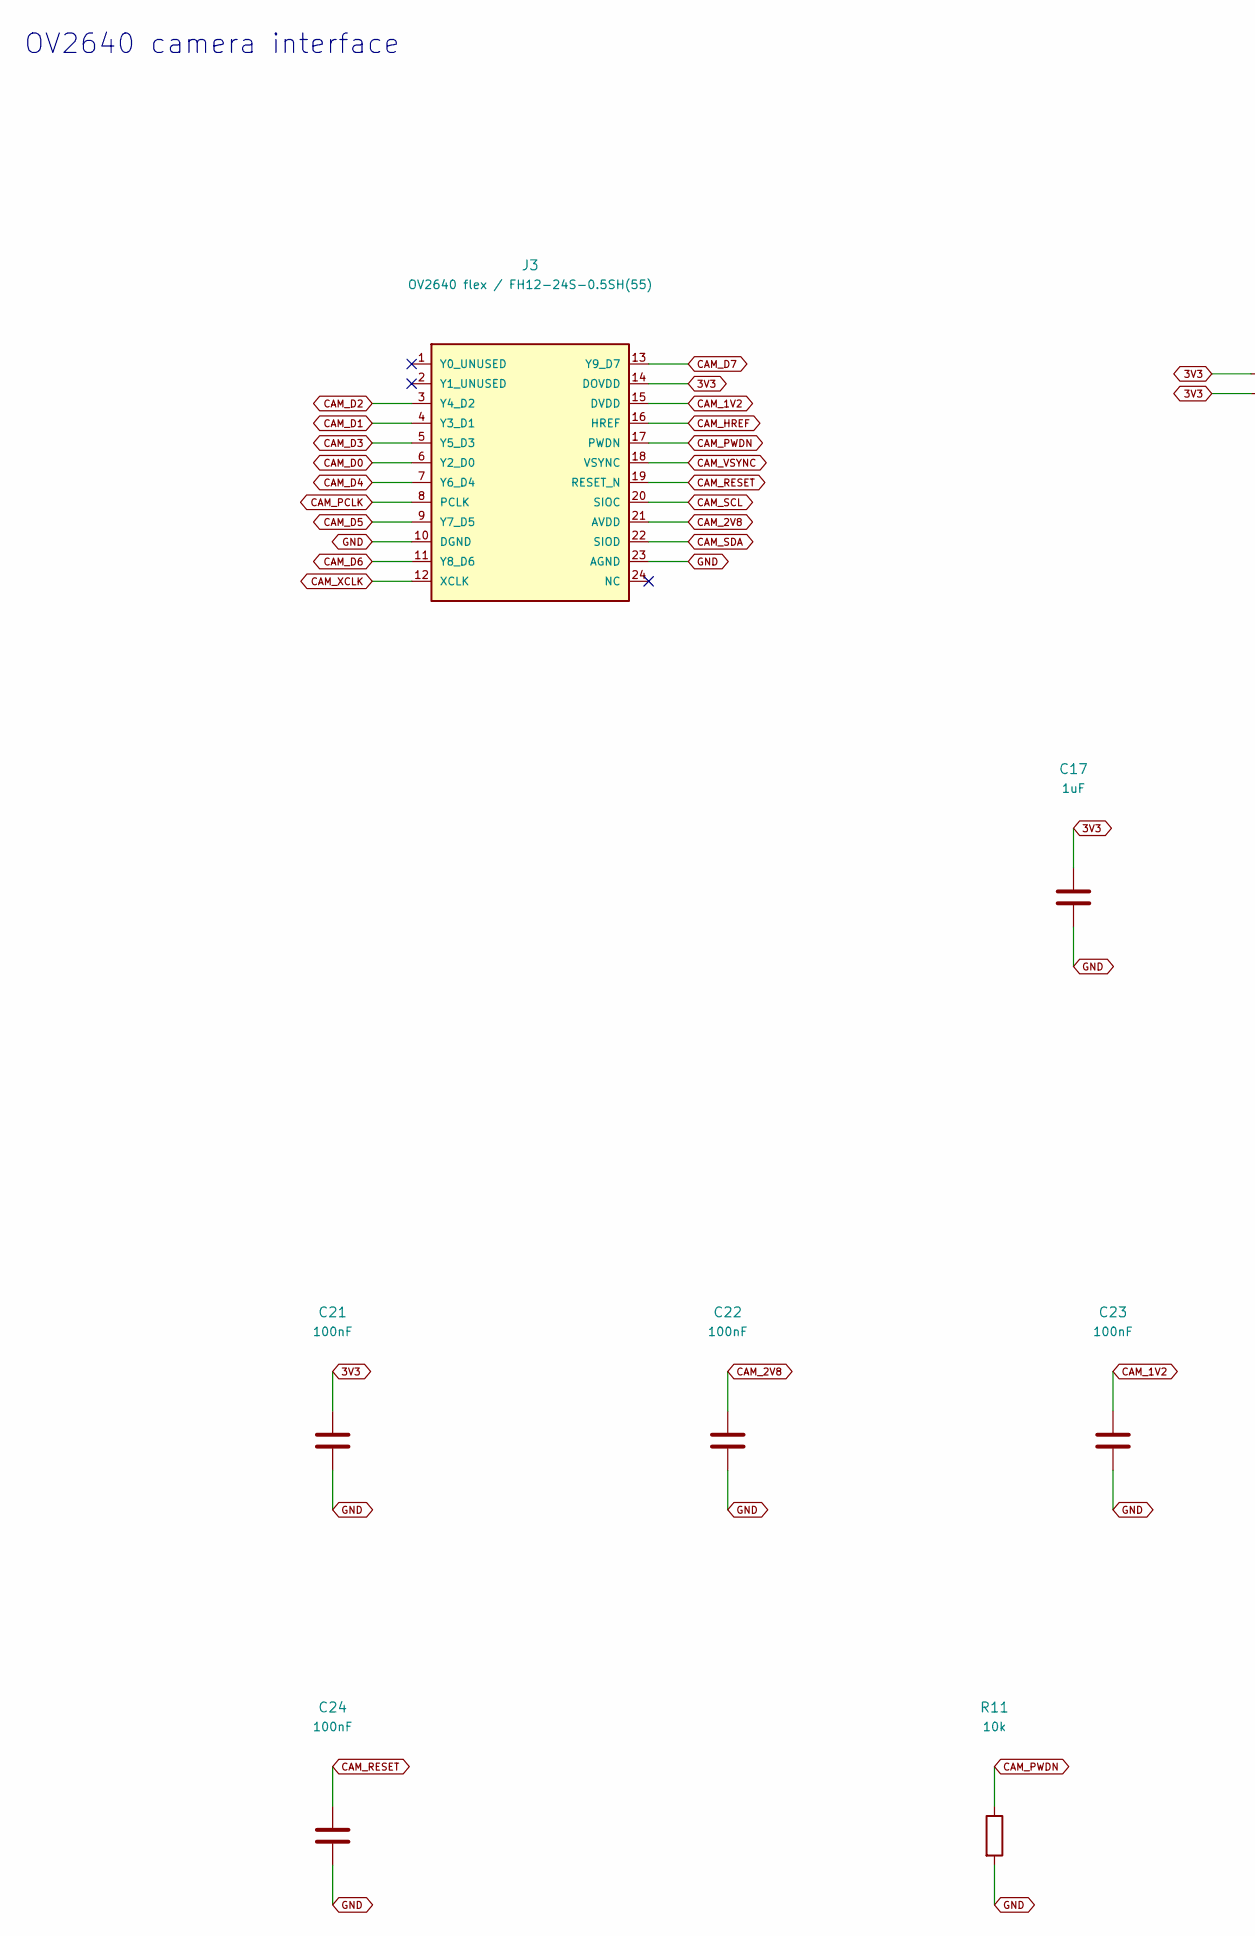
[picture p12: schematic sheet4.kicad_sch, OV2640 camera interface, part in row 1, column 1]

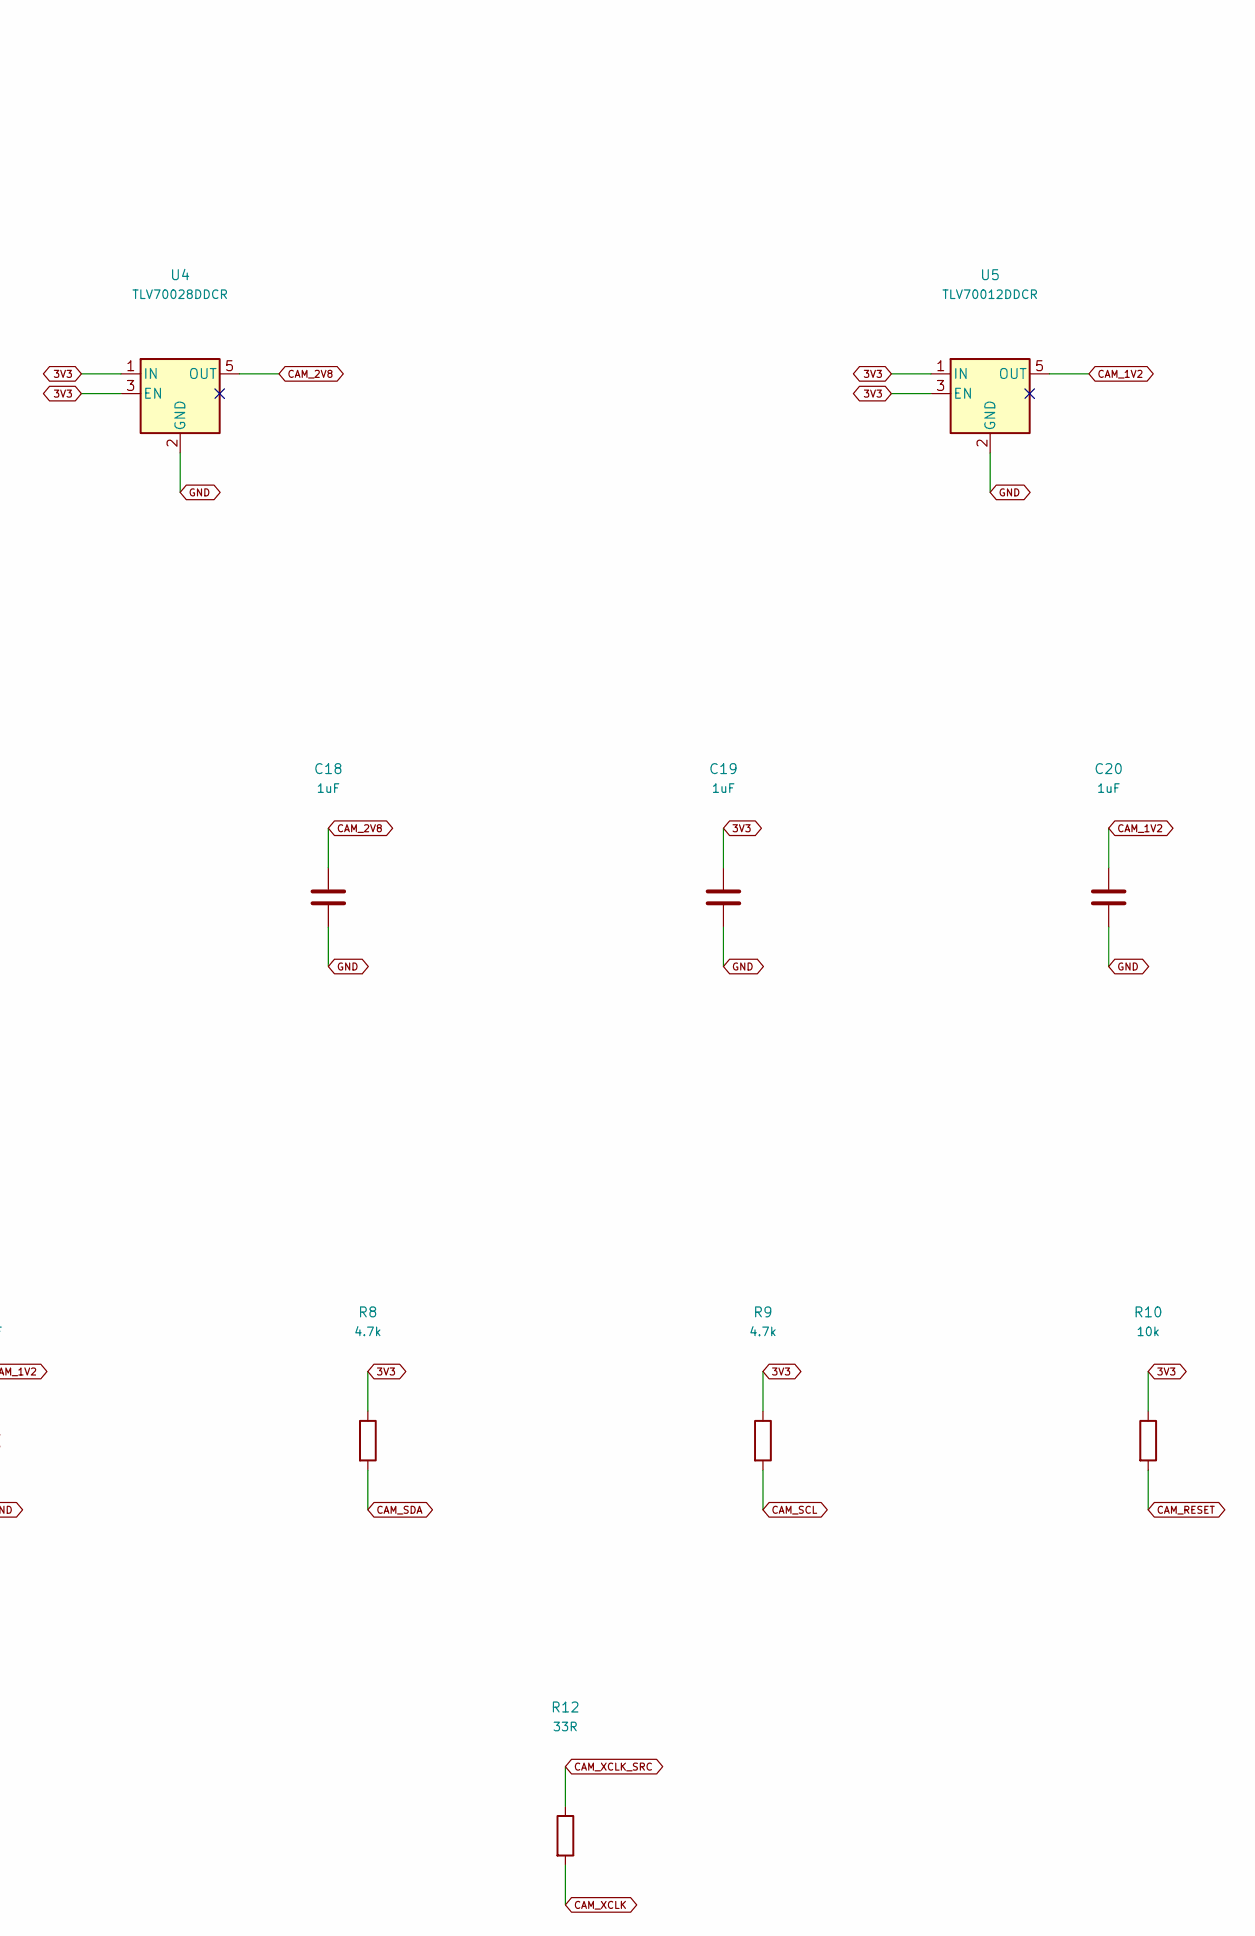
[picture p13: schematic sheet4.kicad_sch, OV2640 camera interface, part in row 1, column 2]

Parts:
C17, C18, C19, C20: 1uF; C_0402_1005Metric
C21, C22, C23, C24: 100nF; C_0402_1005Metric
J3: OV2640 flex / FH12-24S-0.5SH(55); Hirose_FH12-24S-0.5SH_1x24-1MP_P0.50mm_Horizontal
R8, R9: 4.7k; R_0402_1005Metric
R10, R11: 10k; R_0402_1005Metric
R12: 33R; R_0402_1005Metric
U4: TLV70028DDCR; SOT-23-5
U5: TLV70012DDCR; SOT-23-5

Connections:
3V3: C17.1, C19.1, C21.1, J3.14 (DOVDD), R8.1, R9.1, R10.1, U4.1 (IN), U4.3 (EN), U5.1 (IN), U5.3 (EN); also elsewhere on the board
CAM_1V2: C20.1, C23.1, J3.15 (DVDD), U5.5 (OUT)
CAM_2V8: C18.1, C22.1, J3.21 (AVDD), U4.5 (OUT)
CAM_D0: J3.6 (Y2_D0); also elsewhere on the board
CAM_D1: J3.4 (Y3_D1); also elsewhere on the board
CAM_D2: J3.3 (Y4_D2); also elsewhere on the board
CAM_D3: J3.5 (Y5_D3); also elsewhere on the board
CAM_D4: J3.7 (Y6_D4); also elsewhere on the board
CAM_D5: J3.9 (Y7_D5); also elsewhere on the board
CAM_D6: J3.11 (Y8_D6); also elsewhere on the board
CAM_D7: J3.13 (Y9_D7); also elsewhere on the board
CAM_HREF: J3.16 (HREF); also elsewhere on the board
CAM_PCLK: J3.8 (PCLK); also elsewhere on the board
CAM_PWDN: J3.17 (PWDN), R11.1; also elsewhere on the board
CAM_RESET: C24.1, J3.19 (RESET_N), R10.2
CAM_SCL: J3.20 (SIOC), R9.2; also elsewhere on the board
CAM_SDA: J3.22 (SIOD), R8.2; also elsewhere on the board
CAM_VSYNC: J3.18 (VSYNC); also elsewhere on the board
CAM_XCLK: J3.12 (XCLK), R12.2
CAM_XCLK_SRC: R12.1; also elsewhere on the board
GND: C17.2, C18.2, C19.2, C20.2, C21.2, C22.2, C23.2, C24.2, J3.10 (DGND), J3.23 (AGND), R11.2, U4.2 (GND), U5.2 (GND); also elsewhere on the board

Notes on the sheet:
OV2640 camera interface

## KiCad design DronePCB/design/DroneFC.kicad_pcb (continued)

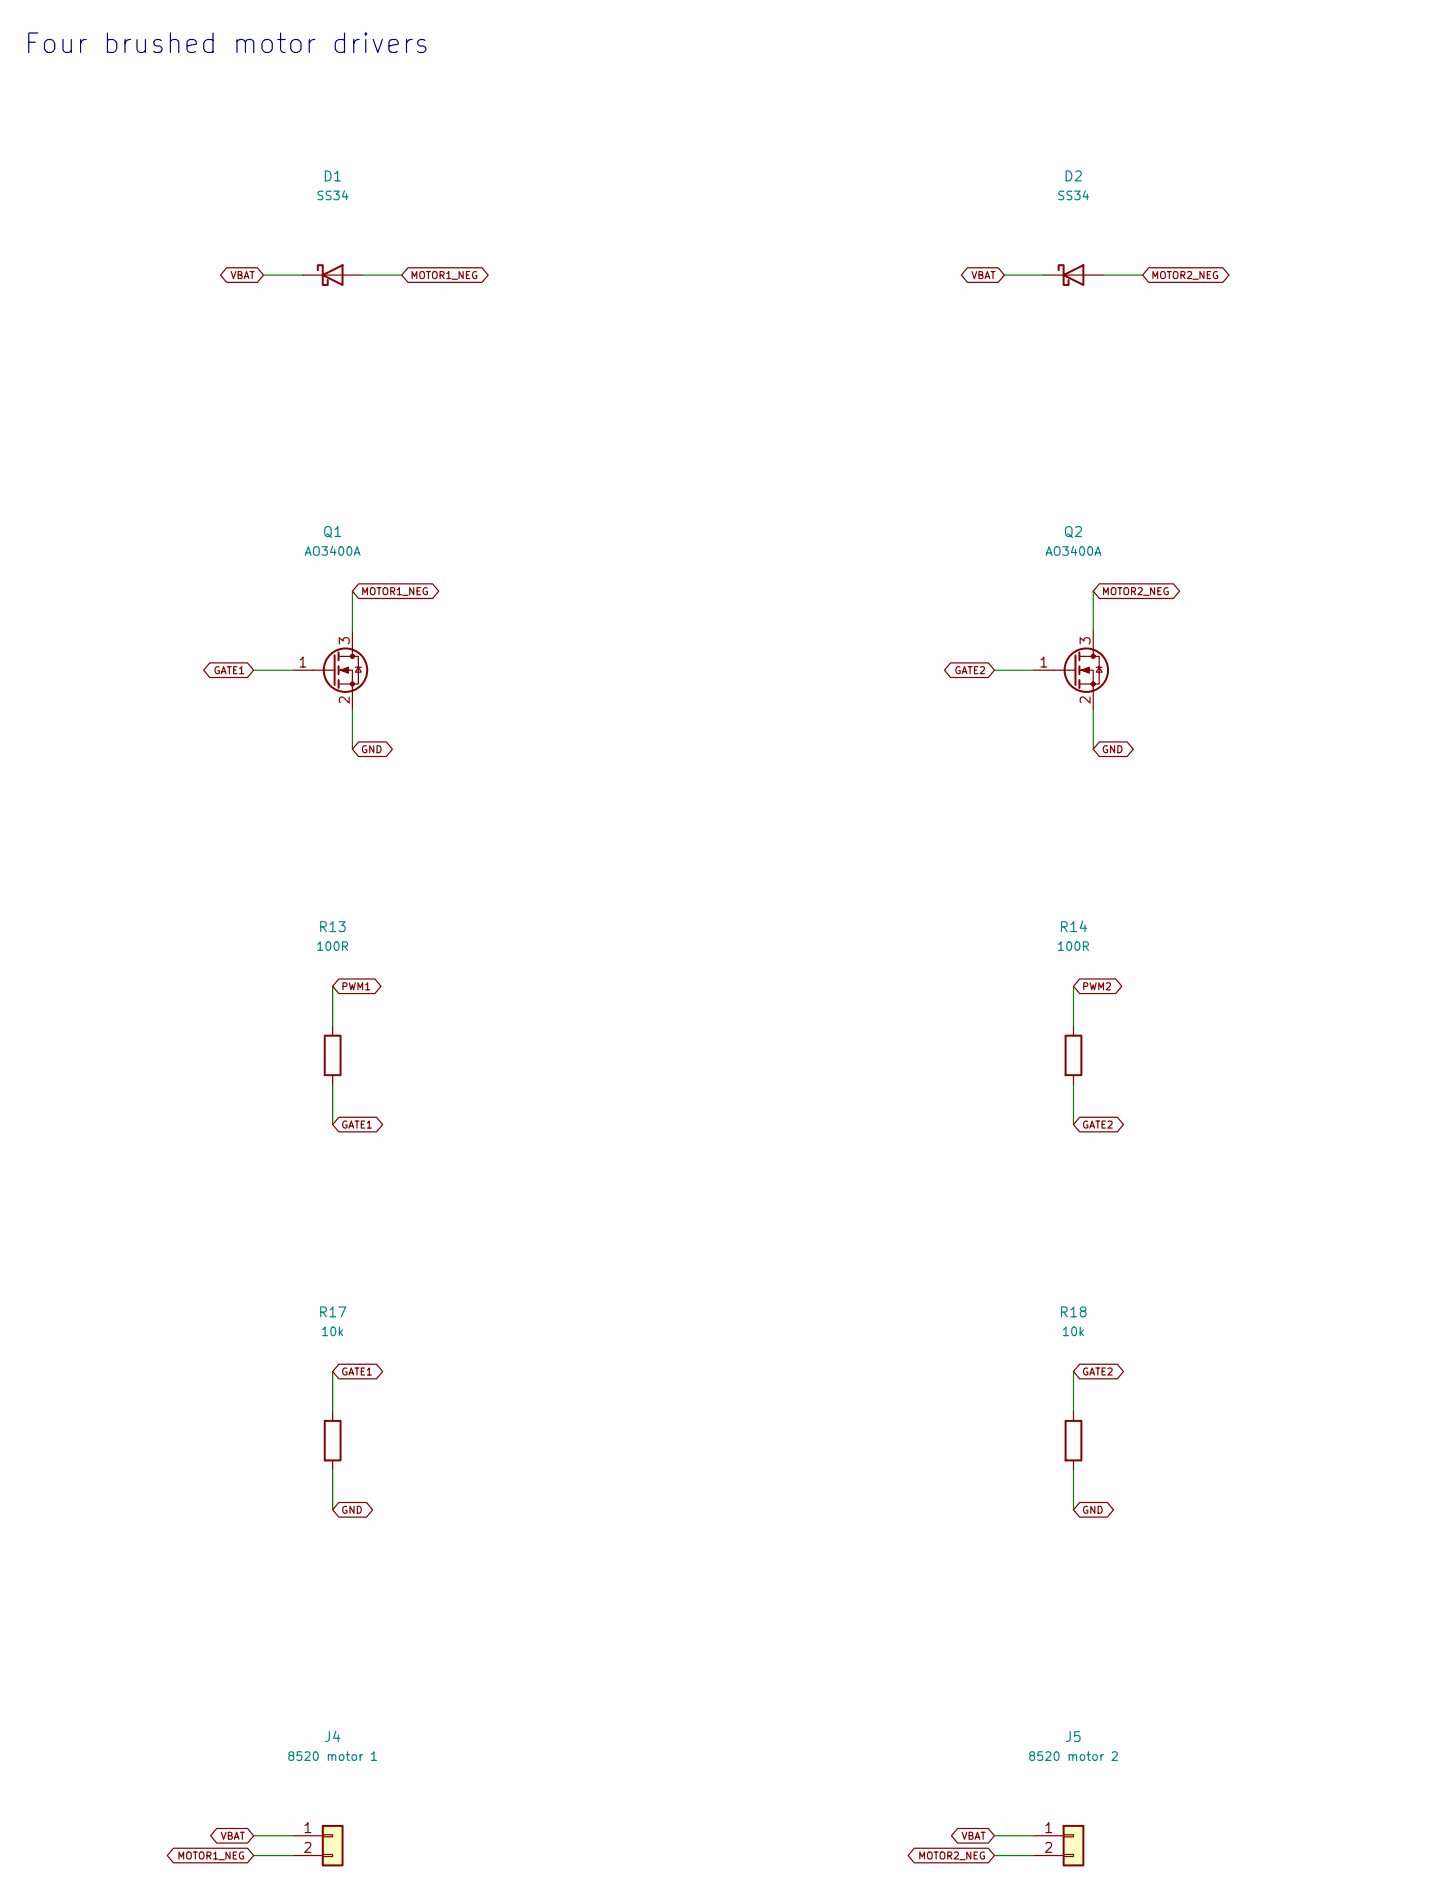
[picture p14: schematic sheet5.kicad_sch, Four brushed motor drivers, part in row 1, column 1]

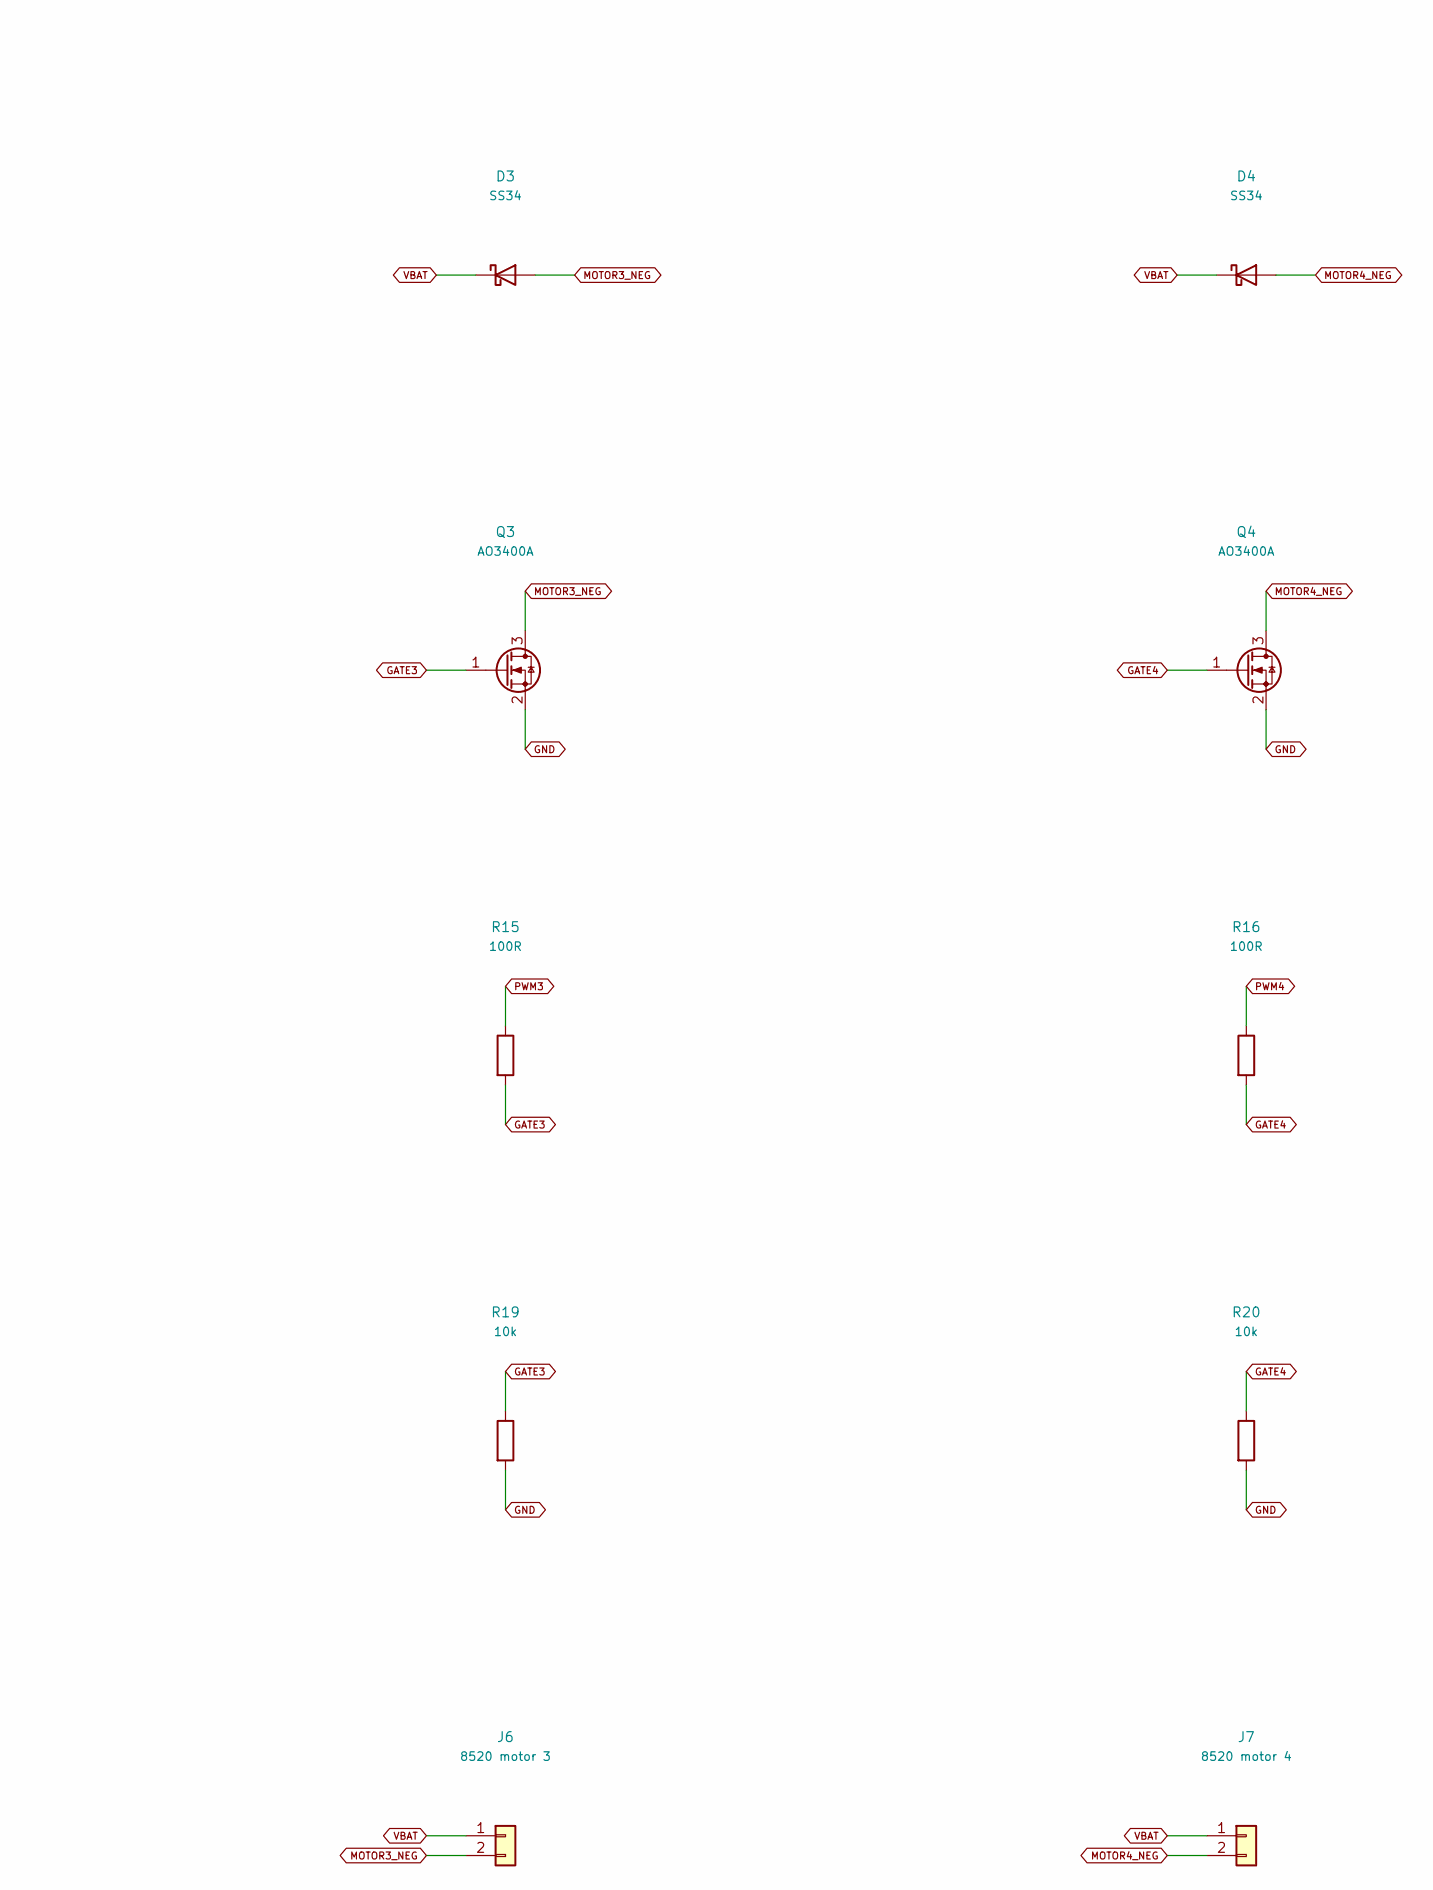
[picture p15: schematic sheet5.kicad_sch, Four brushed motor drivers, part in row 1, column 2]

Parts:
D1, D2, D3, D4: SS34; D_SMA
J4: 8520 motor 1; Motor_2
J5: 8520 motor 2; Motor_2
J6: 8520 motor 3; Motor_2
J7: 8520 motor 4; Motor_2
Q1, Q2, Q3, Q4: AO3400A; SOT-23
R13, R14, R15, R16: 100R; R_0402_1005Metric
R17, R18, R19, R20: 10k; R_0402_1005Metric

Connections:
GATE1: Q1.1 (G), R13.2, R17.1
GATE2: Q2.1 (G), R14.2, R18.1
GATE3: Q3.1 (G), R15.2, R19.1
GATE4: Q4.1 (G), R16.2, R20.1
GND: Q1.2 (S), Q2.2 (S), Q3.2 (S), Q4.2 (S), R17.2, R18.2, R19.2, R20.2; also elsewhere on the board
MOTOR1_NEG: D1.2 (A), J4.2, Q1.3 (D)
MOTOR2_NEG: D2.2 (A), J5.2, Q2.3 (D)
MOTOR3_NEG: D3.2 (A), J6.2, Q3.3 (D)
MOTOR4_NEG: D4.2 (A), J7.2, Q4.3 (D)
PWM1: R13.1; also elsewhere on the board
PWM2: R14.1; also elsewhere on the board
PWM3: R15.1; also elsewhere on the board
PWM4: R16.1; also elsewhere on the board
VBAT: D1.1 (K), D2.1 (K), D3.1 (K), D4.1 (K), J4.1, J5.1, J6.1, J7.1; also elsewhere on the board

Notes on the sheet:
Four brushed motor drivers

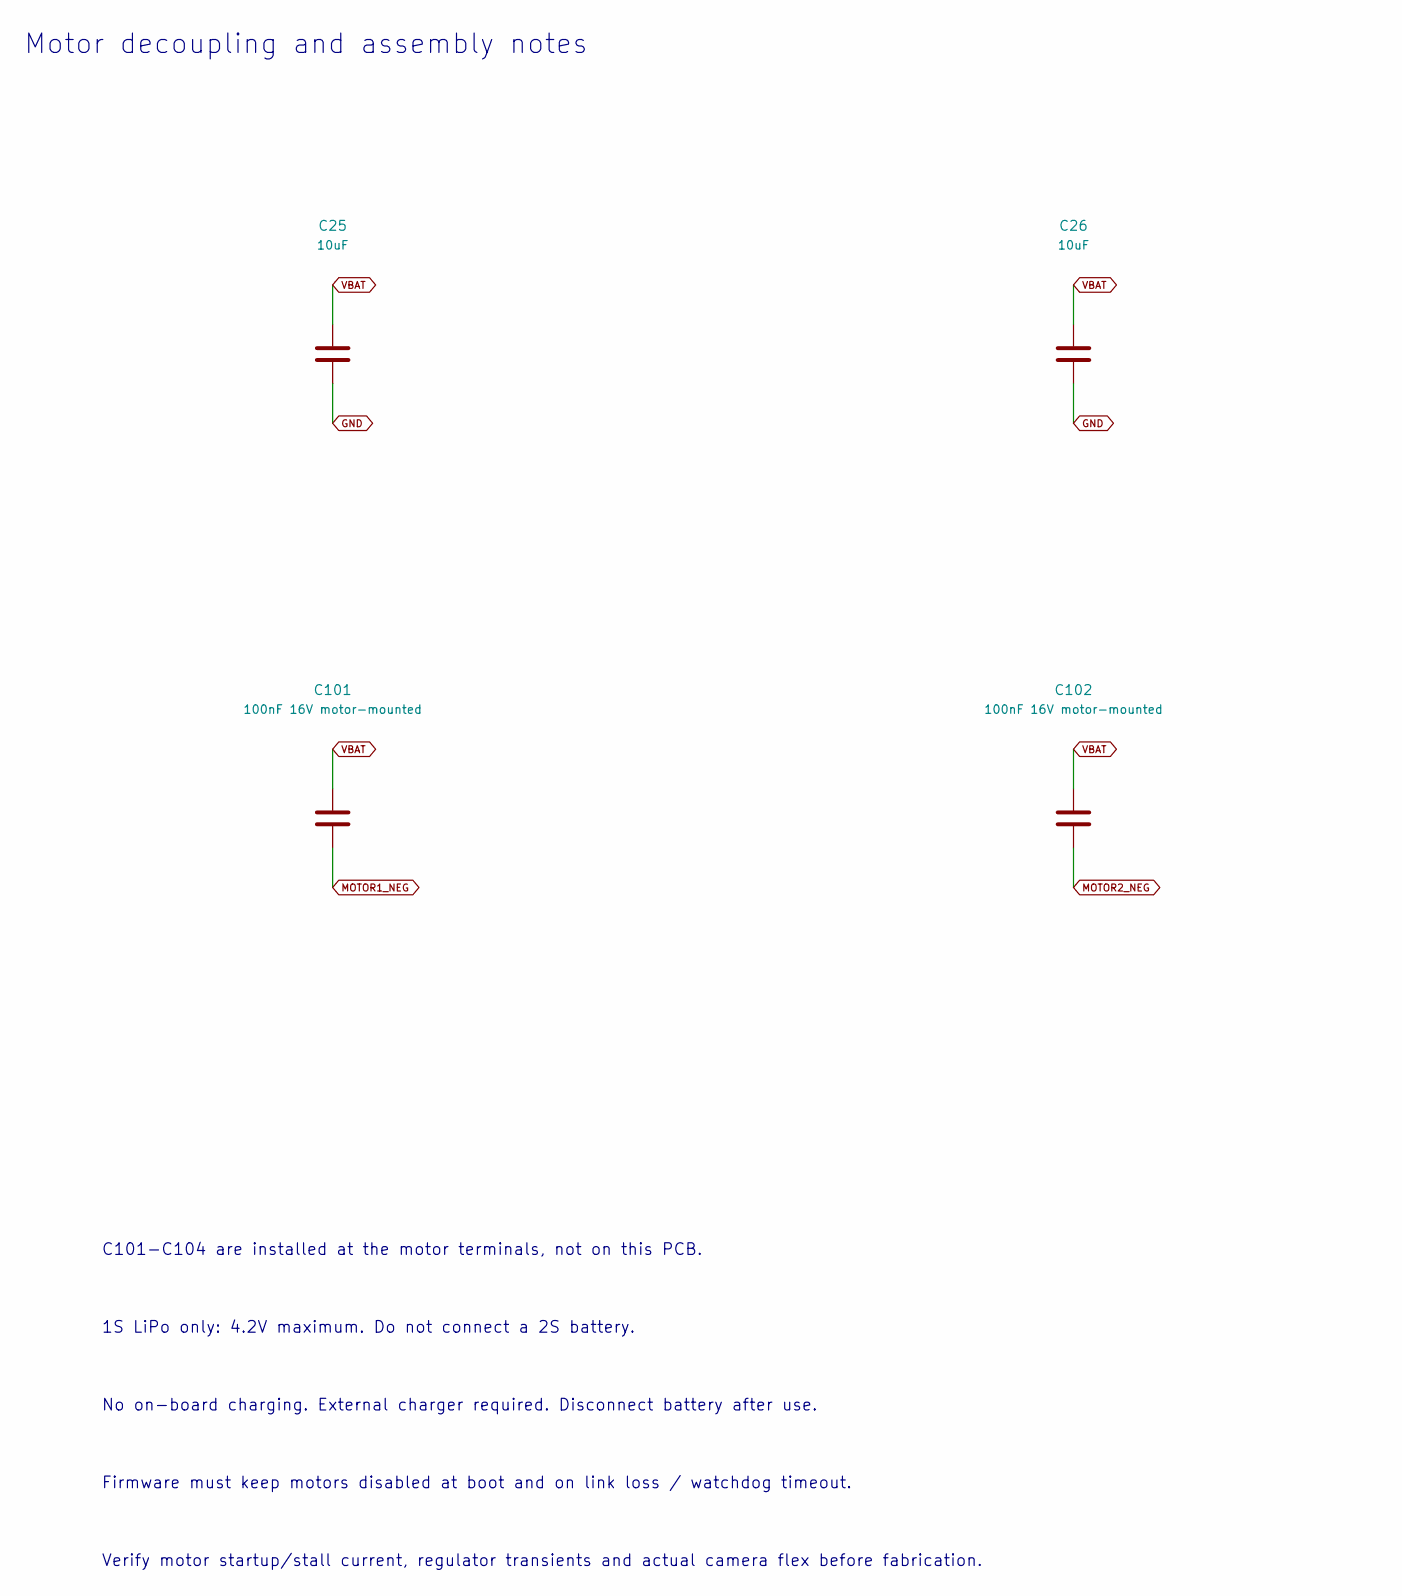
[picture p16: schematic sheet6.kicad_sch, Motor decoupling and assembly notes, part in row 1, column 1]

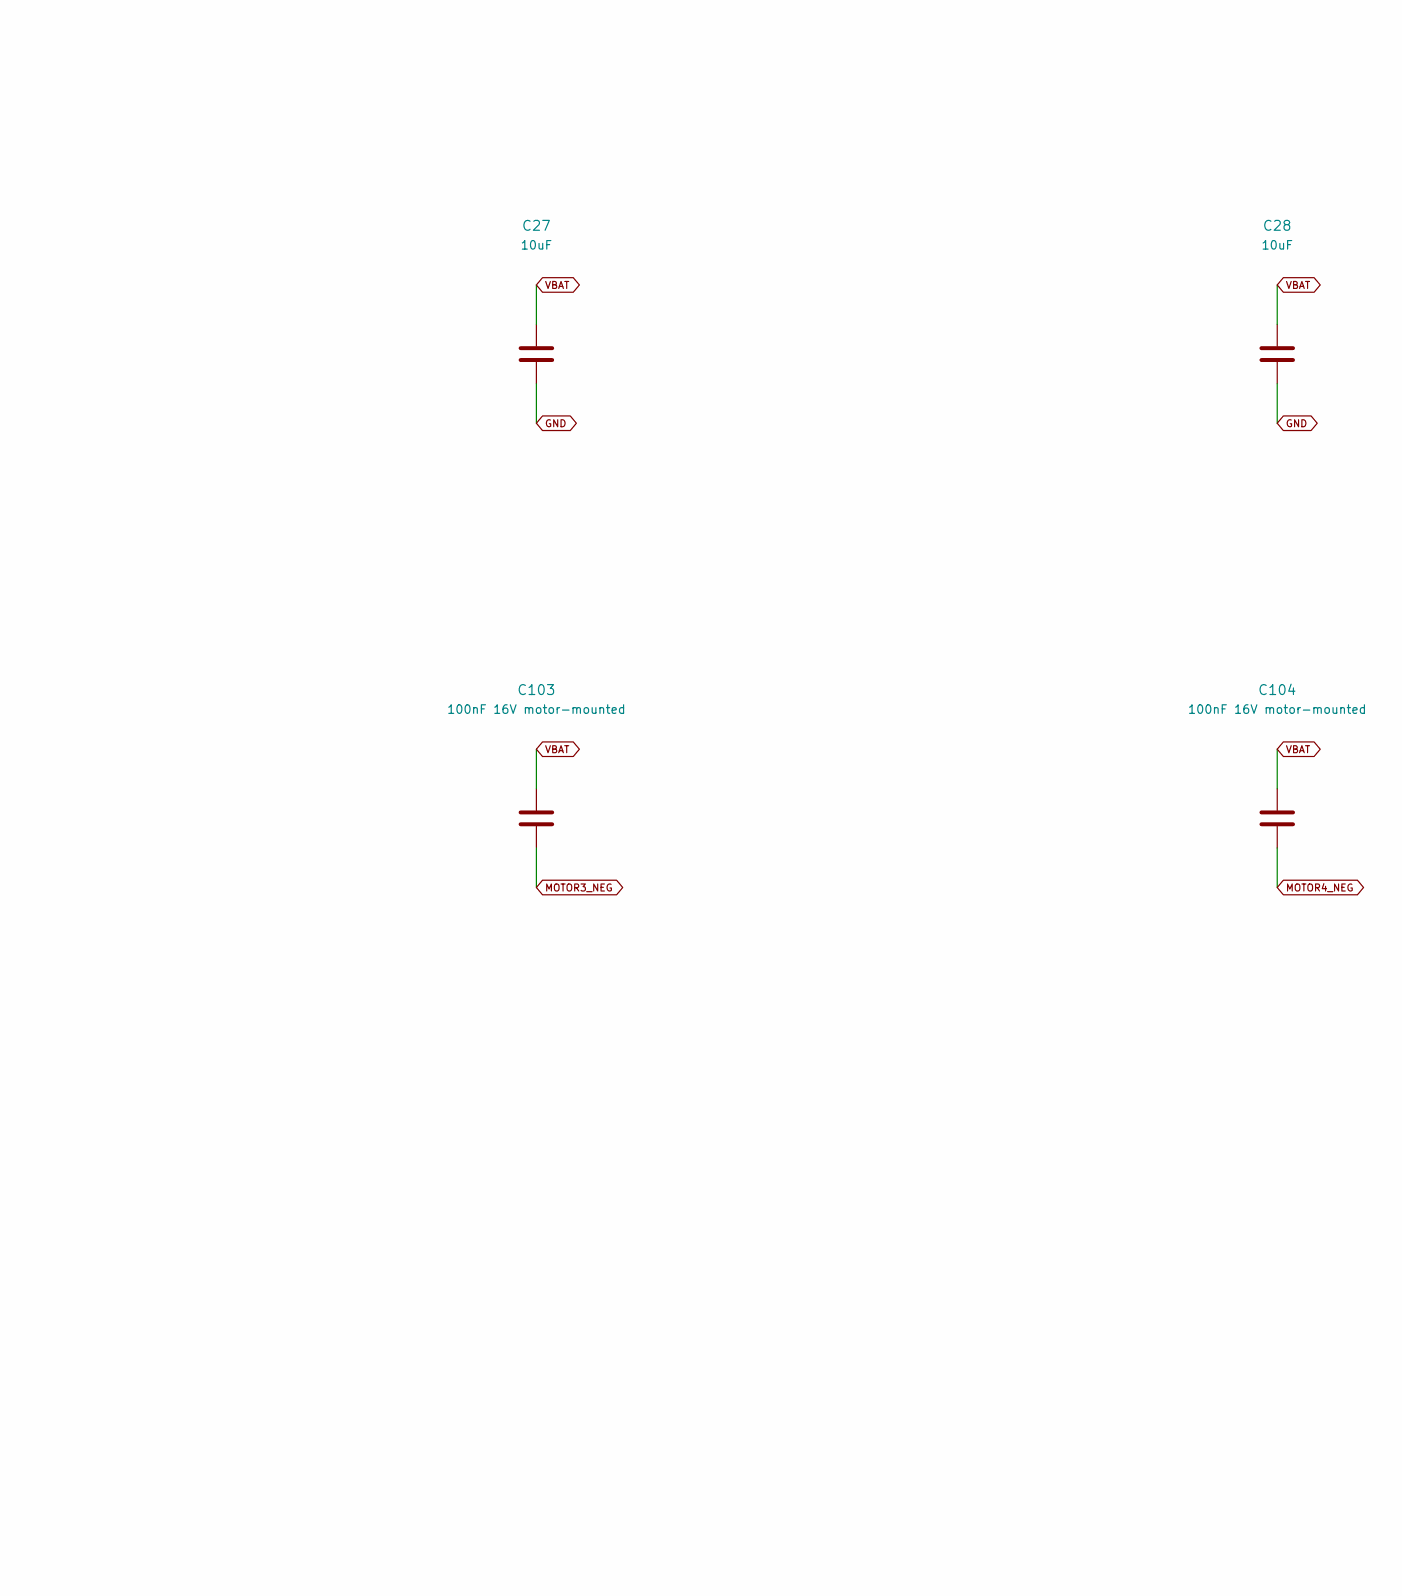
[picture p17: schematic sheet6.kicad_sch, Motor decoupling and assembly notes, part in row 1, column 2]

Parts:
C25, C26, C27, C28: 10uF; C_0603_1608Metric
C101, C102, C103, C104: 100nF 16V motor-mounted

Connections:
GND: C25.2, C26.2, C27.2, C28.2; also elsewhere on the board
VBAT: C25.1, C26.1, C27.1, C28.1, C101.1, C102.1, C103.1, C104.1; also elsewhere on the board

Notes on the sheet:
Motor decoupling and assembly notes
C101-C104 are installed at the motor terminals, not on this PCB.
1S LiPo only: 4.2V maximum. Do not connect a 2S battery.
No on-board charging. External charger required. Disconnect battery after use.
Firmware must keep motors disabled at boot and on link loss / watchdog timeout.
Verify motor startup/stall current, regulator transients and actual camera flex before fabrication.

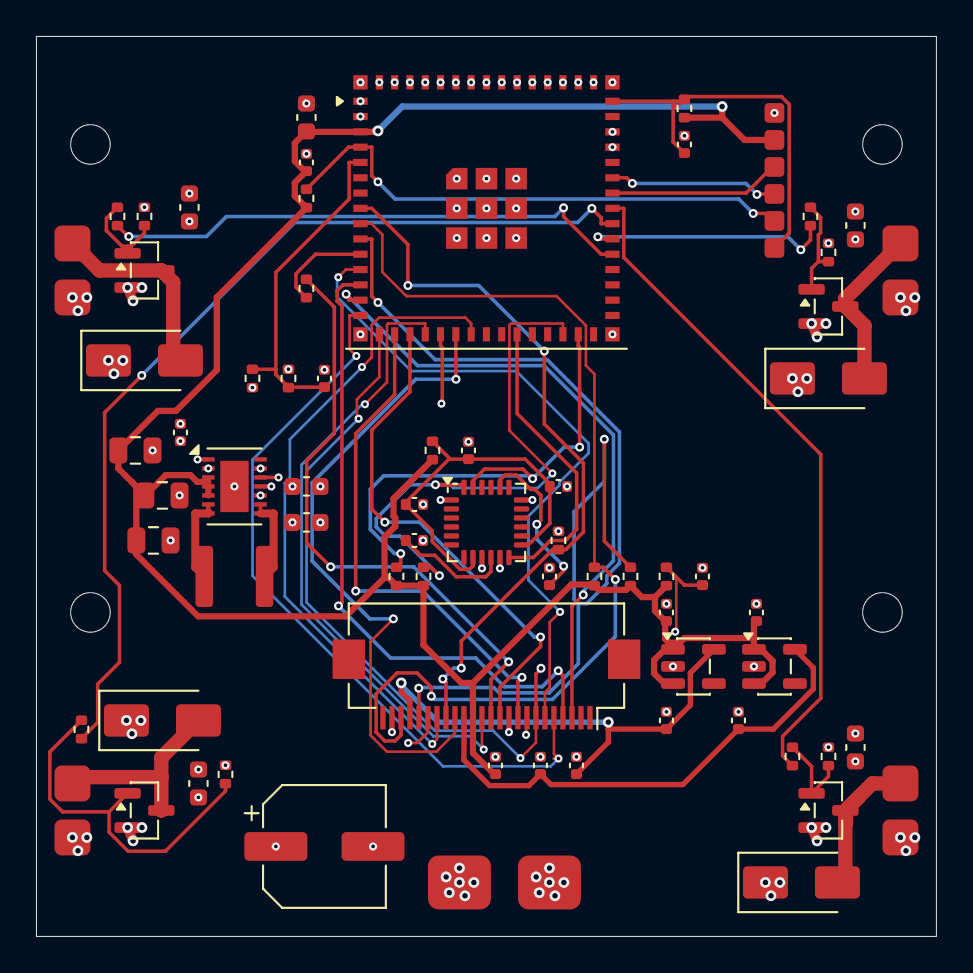
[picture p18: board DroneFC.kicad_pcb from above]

Board: 4 copper layers, 50.0 x 50.0 mm, 73 parts (0 on the bottom side), 47 nets.

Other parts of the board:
H103103, H103147, H147103, H147147: MountingHole_2.2mm_M2

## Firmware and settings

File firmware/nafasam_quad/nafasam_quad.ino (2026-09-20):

// ============================================================================
// Nafasam Mini Quad - Flight Controller Firmware
// Original PCB target: ESP32-S3-MINI-1-N4R2, DroneFC PCB Revision A0 (custom pin map)
//
// Dual-Core FreeRTOS Architecture:
//   Core 0: 200 Hz Flight Control Loop (IMU read -> Fusion -> PID -> Mixer -> PWM)
//   Core 1: WiFi AP ("Nafasam") + esp_http_server (serves web UI, receives /control)
//
// Hardware Pinout (custom map, see config.h):
//   - Motor 1 (J4, Front-Left,  CW):  GPIO 23 (PWM1)
//   - Motor 2 (J5, Front-Right, CCW): GPIO 22 (PWM2)
//   - Motor 3 (J6, Rear-Left,   CCW): GPIO 35 (PWM3)
//   - Motor 4 (J7, Rear-Right,  CW):  GPIO 34 (PWM4)
//   - IMU I2C SDA:                    GPIO 18
//   - IMU I2C SCL:                    GPIO 19
//   - IMU INT:                        GPIO 21
//   - Battery Sense (100k/100k ADC):  GPIO 1  (VBAT_SENSE, unchanged)
//
// Sensor Alignment on DroneFC PCB:
//   PCB Top Edge (ESP32 antenna) = NOSE / FORWARD (+Y drone)
//   PCB Right Edge               = STARBOARD / RIGHT (+X drone)
//   PCB Bottom Edge (Camera FPC) = TAIL / REAR (-Y drone)
//   PCB Left Edge                = PORT / LEFT (-X drone)
//   MPU-6050 (U3) placed at center with rotation 0 (Pin 1 top-left):
//     - Chip +X points to Drone Right
//     - Chip +Y points to Drone Forward (Nose)
//     - Chip +Z points Up (out of the PCB top face)
//
// Angular / Axis Conventions:
//   - Roll:  Right side down = positive angle (Roll > 0).
//            Gravity component along chip -X. Gyro rate = +gy (around nose axis).
//   - Pitch: Nose down (stick forward) = positive angle (Pitch > 0).
//            Gravity component along chip -Y. Gyro rate = -gx (around pitch axis).
//   - Yaw:   Clockwise seen from above = positive yaw rate.
//            Gyro rate = -gz.
// ============================================================================

#include <WiFi.h>
#include <Wire.h>
#include <esp_http_server.h>
#include <math.h>
#include <driver/gpio.h>
#include <esp_system.h>

#include "config.h"
#include "mpu6050.h"
#include "web_page.h"   // Auto-generated from web/public/index.html

// ----------------------------------------------------------------------------
// Shared Thread-Safe Control Command State
// ----------------------------------------------------------------------------

struct ControlCmd {
  uint8_t  throttle;   // 0..100 %
  int8_t   yaw;        // -100..100 % (right = CW)
  int8_t   pitch;      // -100..100 % (forward = +)
  int8_t   roll;       // -100..100 % (right = +)
  bool     armed;      // Arm request from web UI
  uint32_t stamp;      // millis() timestamp of last received packet
};

static ControlCmd g_cmd = {0, 0, 0, 0, false, 0};
static portMUX_TYPE g_cmdMux = portMUX_INITIALIZER_UNLOCKED;

// Real-time telemetry indicators (monitored by HTTP server & loop)
static volatile bool  g_armedActive = false;   // Actual flight loop arming state
static volatile bool  g_imuOk       = false;   // IMU operational status
static volatile float g_dbgRoll     = 0.0f;    // Estimated roll angle (deg)
static volatile float g_dbgPitch    = 0.0f;    // Estimated pitch angle (deg)
static volatile float g_dbgMotor[4] = {0, 0, 0, 0}; // Output duty per motor (0..1)
static volatile float g_vbat        = 0.0f;    // Battery voltage (V)

// ----------------------------------------------------------------------------
// 8520 Motor Drivers (AO3400A Low-Side N-MOSFETs via LEDC PWM)
// ----------------------------------------------------------------------------

enum { M_FL = 0, M_FR = 1, M_RL = 2, M_RR = 3 };
static const uint8_t MOTOR_PINS[4] = {
  PIN_MOTOR_FL, // Motor 1: Front-Left  (CW)  -> GPIO 23
  PIN_MOTOR_FR, // Motor 2: Front-Right (CCW) -> GPIO 22
  PIN_MOTOR_RL, // Motor 3: Rear-Left   (CCW) -> GPIO 35
  PIN_MOTOR_RR  // Motor 4: Rear-Right  (CW)  -> GPIO 34
};

// Per-motor "pin can really output PWM" flags, filled in by motorsInit().
// Some GPIOs are input-only (e.g. GPIO 34..39 on the classic ESP32).
static bool g_motorPinOk[4]  = {false, false, false, false};
static bool g_allMotorsOk    = false;   // Arming is refused unless all 4 are OK

static inline float clampf(float v, float lo, float hi) {
  return (v < lo) ? lo : ((v > hi) ? hi : v);
}

// Drive all 4 motors with normalized duty cycle [0.0 .. 1.0]
static void motorsWrite(const float duty[4]) {
  for (int i = 0; i < 4; i++) {
    float v = clampf(duty[i], 0.0f, MOTOR_MAX_THROTTLE);
    g_dbgMotor[i] = v;
    if (!g_motorPinOk[i]) continue;   // pin cannot output, never touch LEDC
    uint32_t rawDuty = (uint32_t)(v * (float)PWM_MAX_DUTY);
    ledcWrite(MOTOR_PINS[i], rawDuty);
  }
}

// Cut all motor power immediately
static void motorsOff() {
  const float zeros[4] = {0.0f, 0.0f, 0.0f, 0.0f};
  motorsWrite(zeros);
}

// Configure GPIOs and attach LEDC PWM timers
static void motorsInit() {
  g_allMotorsOk = true;

  // CRITICAL HARDWARE SAFETY: Force all motor gate lines LOW before starting peripherals
  for (int i = 0; i < 4; i++) {
    g_motorPinOk[i] = GPIO_IS_VALID_OUTPUT_GPIO((int)MOTOR_PINS[i]);
    if (!g_motorPinOk[i]) {
      Serial.printf("Motors: GPIO %d (motor %d) cannot be used as an output on this chip!\n",
                    MOTOR_PINS[i], i + 1);
      g_allMotorsOk = false;
      continue;
    }
    pinMode(MOTOR_PINS[i], OUTPUT);
    digitalWrite(MOTOR_PINS[i], LOW);
  }

  // Attach LEDC PWM channels (Arduino ESP32 Core v3.x API)
  for (int i = 0; i < 4; i++) {
    if (!g_motorPinOk[i]) continue;
    if (!ledcAttach(MOTOR_PINS[i], PWM_FREQ_HZ, PWM_RES_BITS)) {
      Serial.printf("Motors: LEDC attach failed on GPIO %d (motor %d)\n", MOTOR_PINS[i], i + 1);
      g_motorPinOk[i] = false;
      g_allMotorsOk = false;
    }
  }

  motorsOff();

  if (!g_allMotorsOk) {
    Serial.println("Motors: ARMING DISABLED until all 4 motor pins are valid outputs (see config.h)");
  }
}

// ----------------------------------------------------------------------------
// Battery Voltage Monitor
// ----------------------------------------------------------------------------

static float readBatteryVoltage() {
  // Calibrated ADC readout in millivolts
  uint32_t mv = analogReadMilliVolts(PIN_BATTERY_ADC);
  return (float)mv * BATTERY_DIVIDER_RATIO / 1000.0f;
}

// ----------------------------------------------------------------------------
// IMU (MPU-6050) & Sensor Alignment
// ----------------------------------------------------------------------------

static Mpu6050 mpu;

static const float RAD2DEG = 57.2957795f;

// Accelerometer attitude angles mapped specifically to DroneFC PCB orientation:
//   Chip +X = Right, Chip +Y = Nose, Chip +Z = Up
static inline float accelRoll(const MpuData &d) {
  // Rolling right causes gravity reaction vector to tilt left (-X)
  return atan2f(-d.ax, d.az) * RAD2DEG;
}

static inline float accelPitch(const MpuData &d) {
  // Pitching forward causes gravity reaction vector to tilt backwards (-Y)
  return atan2f(-d.ay, sqrtf(d.ax * d.ax + d.az * d.az)) * RAD2DEG;
}

// Initialize I2C bus and calibrate MPU-6050 on a flat surface
static bool imuStartup(ImuCal &cal) {
  Wire.end();
  Wire.begin(PIN_I2C_SDA, PIN_I2C_SCL, I2C_FREQ_HZ);
  Wire.setTimeOut(I2C_TIMEOUT_MS);

  if (!mpu.begin(Wire, DRONE_IMU_I2C_ADDR)) {
    Serial.printf("MPU-6050: Connection failed! Check wiring on SDA:GPIO%d, SCL:GPIO%d\n",
                  PIN_I2C_SDA, PIN_I2C_SCL);
    return false;
  }

  Serial.println("MPU-6050: Calibrating (Keep drone FLAT and STILL)...");

  const int SAMPLES = 300;
  double sumGyro[3] = {0.0, 0.0, 0.0};
  double sumRoll = 0.0;
  double sumPitch = 0.0;

  for (int i = 0; i < SAMPLES; i++) {
    MpuData d;
    if (!mpu.read(d)) {
      Serial.println("MPU-6050: Read failed during calibration");
      return false;
    }
    sumGyro[0] += d.gx;
    sumGyro[1] += d.gy;
    sumGyro[2] += d.gz;
    sumRoll    += accelRoll(d);
    sumPitch   += accelPitch(d);
    vTaskDelay(pdMS_TO_TICKS(3));
  }

  for (int i = 0; i < 3; i++) {
    cal.gyroBias[i] = (float)(sumGyro[i] / SAMPLES);
  }
  cal.rollOffset  = (float)(sumRoll  / SAMPLES);
  cal.pitchOffset = (float)(sumPitch / SAMPLES);

  // If gyro bias is abnormally large, the board was likely moving
  if (fabsf(cal.gyroBias[0]) > 25.0f || fabsf(cal.gyroBias[1]) > 25.0f || fabsf(cal.gyroBias[2]) > 25.0f) {
    Serial.println("MPU-6050: Calibration rejected (movement detected). Retrying...");
    return false;
  }

  Serial.printf("MPU-6050: Ready! Gyro Bias: X=%.2f Y=%.2f Z=%.2f dps | Trim: R=%.1f P=%.1f deg\n",
                cal.gyroBias[0], cal.gyroBias[1], cal.gyroBias[2],
                cal.rollOffset, cal.pitchOffset);
  return true;
}

// ----------------------------------------------------------------------------
// Core 0 FreeRTOS Flight Task (200 Hz Stabilisation & Motor Mixer)
// ----------------------------------------------------------------------------

static void flightTask(void *param) {
  (void)param;
  ImuCal cal = {};
  bool imuReady   = false;
  bool armed      = false;
  bool armLock    = false;   // Safety interlock: must see armed=0 before enabling arm
  uint8_t failCnt = 0;
  uint32_t lastRetryMs = 0;
  uint32_t lastLoopUs  = micros();

  float rollAngle  = 0.0f;
  float pitchAngle = 0.0f;
  float iRoll      = 0.0f;
  float iPitch     = 0.0f;

  TickType_t nextWakeTime = xTaskGetTickCount();

  for (;;) {
    vTaskDelayUntil(&nextWakeTime, pdMS_TO_TICKS(LOOP_PERIOD_MS));

    // 1. Ensure IMU is initialized and calibrated
    if (!imuReady) {
      motorsOff();
      g_imuOk = false;
      g_armedActive = false;
      armed = false;

      if (millis() - lastRetryMs >= IMU_RETRY_MS) {
        lastRetryMs = millis();
        imuReady = imuStartup(cal);
        if (imuReady) {
          rollAngle  = 0.0f;
          pitchAngle = 0.0f;
          iRoll      = 0.0f;
          iPitch     = 0.0f;
          failCnt    = 0;
          lastLoopUs = micros();
          g_imuOk    = true;
        }
      }
      continue;
    }

    // 2. Read IMU sensor data
    MpuData d;
    if (!mpu.read(d)) {
      motorsOff();
      g_armedActive = false;
      armed = false;
      armLock = true;
      if (++failCnt >= IMU_FAIL_LIMIT) {
        Serial.println("MPU-6050: Lost bus communication, resetting IMU");
        imuReady = false;
        lastRetryMs = 0;
      }
      continue;
    }
    failCnt = 0;

    // 3. Compute delta time
    uint32_t nowUs = micros();
    float dt = (float)(nowUs - lastLoopUs) * 1e-6f;
    lastLoopUs = nowUs;
    if (dt <= 0.0f || dt > 0.05f) {
      dt = (float)LOOP_PERIOD_MS * 1e-3f;
    }

    // 4. Map sensor axes to Drone Body Frame
    // On DroneFC PCB:
    //   Roll rate is rotation about Forward (+Y) axis: gy
    //   Pitch rate is rotation about Lateral (+X) axis: nose down is -gx
    //   Yaw rate is rotation about Vertical (+Z) axis: CW rotation is -gz
    float gyroRollRate  =  (d.gy - cal.gyroBias[1]);
    float gyroPitchRate = -(d.gx - cal.gyroBias[0]);
    float gyroYawRate   = -(d.gz - cal.gyroBias[2]);

    // 5. Sensor Fusion (Complementary Filter)
    float accR = accelRoll(d)  - cal.rollOffset;
    float accP = accelPitch(d) - cal.pitchOffset;

    rollAngle  = COMPLEMENTARY_ALPHA * (rollAngle  + gyroRollRate  * dt) + (1.0f - COMPLEMENTARY_ALPHA) * accR;
    pitchAngle = COMPLEMENTARY_ALPHA * (pitchAngle + gyroPitchRate * dt) + (1.0f - COMPLEMENTARY_ALPHA) * accP;

    g_dbgRoll  = rollAngle;
    g_dbgPitch = pitchAngle;

    // 6. Fetch latest control command snapshot (thread-safe)
    ControlCmd cmd;
    portENTER_CRITICAL(&g_cmdMux);
    cmd = g_cmd;
    portEXIT_CRITICAL(&g_cmdMux);

    // 7. Safety checks and failsafes
    // Check for link loss (timeout > 500 ms)
    bool linkActive = (cmd.stamp != 0) && ((millis() - cmd.stamp) < FAILSAFE_MS);
    if (!linkActive) {
      if (armed) armLock = true;
      cmd.armed    = false;
      cmd.throttle = 0;
    } else if (!cmd.armed) {
      armLock = false; // Disarmed from phone, reset lock
    }

    // Arming interlocks:
    // - Refuse to arm if throttle stick is raised (> 5%)
    // - Refuse to arm if drone is currently flipped (> 65 degrees)
    bool wantArm = cmd.armed && !armLock;
    if (wantArm && !armed && cmd.throttle > ARM_MAX_THROTTLE) {
      armLock = true;
      wantArm = false;
    }
    if (wantArm && (fabsf(rollAngle) > CRASH_ANGLE_DEG || fabsf(pitchAngle) > CRASH_ANGLE_DEG)) {
      armLock = true;
      wantArm = false;
    }

    // - Refuse to arm if any motor pin cannot drive an output (checked at boot)
    if (wantArm && !g_allMotorsOk) {
      armLock = true;
      wantArm = false;
    }

    armed = wantArm;
    g_armedActive = armed;

    // If disarmed or below throttle deadband, cut all motors
    if (!armed || cmd.throttle < THROTTLE_DEADBAND) {
      motorsOff();
      iRoll  = 0.0f;
      iPitch = 0.0f;
      continue;
    }

    // 8. Flight Control PID
    // Desired setpoints from web joystick commands:
    float spRoll    = (cmd.roll  / 100.0f) * MAX_TILT_DEG;
    float spPitch   = (cmd.pitch / 100.0f) * MAX_TILT_DEG;
    float spYawRate = (cmd.yaw   / 100.0f) * MAX_YAW_RATE_DPS;

    // Angle errors:
    float errRoll  = spRoll  - rollAngle;
    float errPitch = spPitch - pitchAngle;

    // Integrator with anti-windup:
    iRoll  = clampf(iRoll  + errRoll  * KI_ANGLE * dt, -I_LIMIT, I_LIMIT);
    iPitch = clampf(iPitch + errPitch * KI_ANGLE * dt, -I_LIMIT, I_LIMIT);

    // PID outputs (Derivative on measurement damping):
    float outRoll  = clampf(KP_ANGLE * errRoll  + iRoll  - KD_ANGLE * gyroRollRate,  -PID_OUT_LIMIT, PID_OUT_LIMIT);
    float outPitch = clampf(KP_ANGLE * errPitch + iPitch - KD_ANGLE * gyroPitchRate, -PID_OUT_LIMIT, PID_OUT_LIMIT);
    float outYaw   = clampf(KP_YAW_RATE * (spYawRate - gyroYawRate), -YAW_OUT_LIMIT, YAW_OUT_LIMIT);

    // 9. X-Configuration Motor Mixer for 8520 Brushed Motors:
    //   - FL (J4, Motor 1, CW):  base - pitch + roll - yaw
    //   - FR (J5, Motor 2, CCW): base - pitch - roll + yaw
    //   - RL (J6, Motor 3, CCW): base + pitch + roll + yaw
    //   - RR (J7, Motor 4, CW):  base + pitch - roll - yaw
    float baseThrottle = cmd.throttle / 100.0f;
    float motorPwm[4];

    motorPwm[M_FL] = baseThrottle - outPitch + outRoll - outYaw;
    motorPwm[M_FR] = baseThrottle - outPitch - outRoll + outYaw;
    motorPwm[M_RL] = baseThrottle + outPitch + outRoll + outYaw;
    motorPwm[M_RR] = baseThrottle + outPitch - outRoll - outYaw;

    motorsWrite(motorPwm);
  }
}

// ----------------------------------------------------------------------------
// Core 1 HTTP Server Handlers
// ----------------------------------------------------------------------------

static bool queryInt(const char *queryString, const char *key, int minVal, int maxVal, int &outVal) {
  char buf[16];
  if (httpd_query_key_value(queryString, key, buf, sizeof(buf)) != ESP_OK) return false;
  int v = atoi(buf);
  outVal = (v < minVal) ? minVal : ((v > maxVal) ? maxVal : v);
  return true;
}

// Serve touch controller web page
static esp_err_t handleRoot(httpd_req_t *req) {
  httpd_resp_set_type(req, "text/html");
  httpd_resp_set_hdr(req, "Cache-Control", "no-cache, no-store, must-revalidate");
  return httpd_resp_send(req, index_html, HTTPD_RESP_USE_STRLEN);
}

// Handle periodic control polling: /control?throttle=..&yaw=..&pitch=..&roll=..&armed=..
static esp_err_t handleControl(httpd_req_t *req) {
  char query[128];
  int t = 0, y = 0, p = 0, r = 0, a = 0;

  if (httpd_req_get_url_query_str(req, query, sizeof(query)) != ESP_OK ||
      !queryInt(query, "throttle", 0, 100, t) ||
      !queryInt(query, "yaw", -100, 100, y) ||
      !queryInt(query, "pitch", -100, 100, p) ||
      !queryInt(query, "roll", -100, 100, r) ||
      !queryInt(query, "armed", 0, 1, a)) {
    httpd_resp_send_err(req, HTTPD_400_BAD_REQUEST, "Invalid control query");
    return ESP_OK;
  }

  // Update control state with atomic lock
  portENTER_CRITICAL(&g_cmdMux);
  g_cmd.throttle = (uint8_t)t;
  g_cmd.yaw      = (int8_t)y;
  g_cmd.pitch    = (int8_t)p;
  g_cmd.roll     = (int8_t)r;
  g_cmd.armed    = (a == 1);
  g_cmd.stamp    = millis();
  portEXIT_CRITICAL(&g_cmdMux);

  // Return telemetry JSON including IMU health, armed status, and battery voltage
  char body[64];
  snprintf(body, sizeof(body),
           "{\"armed\":%d,\"imu\":%d,\"vbat\":%.2f}",
           g_armedActive ? 1 : 0,
           g_imuOk ? 1 : 0,
           g_vbat);

  httpd_resp_set_type(req, "application/json");
  httpd_resp_set_hdr(req, "Cache-Control", "no-store");
  return httpd_resp_send(req, body, HTTPD_RESP_USE_STRLEN);
}

static esp_err_t handleFavicon(httpd_req_t *req) {
  httpd_resp_set_status(req, "204 No Content");
  return httpd_resp_send(req, nullptr, 0);
}

// Redirect captive portal checks to main control interface
static esp_err_t handleCaptive(httpd_req_t *req) {
  httpd_resp_set_status(req, "302 Found");
  httpd_resp_set_hdr(req, "Location", "http://192.168.4.1/");
  return httpd_resp_send(req, nullptr, 0);
}

static void startWebServer() {
  httpd_config_t config = HTTPD_DEFAULT_CONFIG();
  config.server_port = 80;
  config.core_id     = 1;
  config.lru_purge_enable = true;

  httpd_handle_t server = nullptr;
  if (httpd_start(&server, &config) != ESP_OK) {
    Serial.println("Web Server: Initialization failed!");
    return;
  }

  httpd_uri_t uriRoot = { "/", HTTP_GET, handleRoot, nullptr };
  httpd_register_uri_handler(server, &uriRoot);

  httpd_uri_t uriControl = { "/control", HTTP_GET, handleControl, nullptr };
  httpd_register_uri_handler(server, &uriControl);

  httpd_uri_t uriFavicon = { "/favicon.ico", HTTP_GET, handleFavicon, nullptr };
  httpd_register_uri_handler(server, &uriFavicon);

  // Captive portal probes for iOS and Android
  httpd_uri_t uriHotspot = { "/hotspot-detect.html", HTTP_GET, handleRoot, nullptr };
  httpd_register_uri_handler(server, &uriHotspot);

  httpd_uri_t uriGen204 = { "/generate_204", HTTP_GET, handleCaptive, nullptr };
  httpd_register_uri_handler(server, &uriGen204);

  Serial.println("Web Server: Active on port 80");
}

// ----------------------------------------------------------------------------
// Arduino Setup & Loop
// ----------------------------------------------------------------------------

static const char *resetReasonStr(esp_reset_reason_t r) {
  switch (r) {
    case ESP_RST_POWERON:   return "POWERON";
    case ESP_RST_SW:        return "SOFTWARE";
    case ESP_RST_PANIC:     return "PANIC (crash)";
    case ESP_RST_INT_WDT:   return "INTERRUPT WATCHDOG";
    case ESP_RST_TASK_WDT:  return "TASK WATCHDOG";
    case ESP_RST_WDT:       return "OTHER WATCHDOG";
    case ESP_RST_BROWNOUT:  return "BROWNOUT (power supply too weak)";
    default:                return "OTHER";
  }
}

void setup() {
  Serial.begin(115200);
  delay(100);
  Serial.printf("\nReset reason: %s\n", resetReasonStr(esp_reset_reason()));

  Serial.println("\n=============================================");
  Serial.println("   Nafasam Mini Quad - Flight Controller");
  Serial.println("   Hardware: ESP32 (custom pin map)");
  Serial.println("=============================================");

  // 1. Initialize motor PWM pins (immediate LOW state for MOSFET safety)
  motorsInit();
  Serial.printf("Motors: Attached on GPIOs FL:%d FR:%d RL:%d RR:%d @ %d Hz\n",
                PIN_MOTOR_FL, PIN_MOTOR_FR, PIN_MOTOR_RL, PIN_MOTOR_RR, PWM_FREQ_HZ);

  // 2. Configure battery ADC input
  analogSetPinAttenuation(PIN_BATTERY_ADC, ADC_11db);
  g_vbat = readBatteryVoltage();
  Serial.printf("Battery: Initial voltage = %.2f V\n", g_vbat);

  // 3. Start WiFi Access Point
  WiFi.mode(WIFI_AP);
  bool apOk = false;
  for (int attempt = 1; attempt <= 3 && !apOk; attempt++) {
    apOk = WiFi.softAP(AP_SSID, strlen(AP_PASSWORD) ? AP_PASSWORD : nullptr, AP_CHANNEL, 0, AP_MAX_CONN);
    if (!apOk) {
      Serial.printf("WiFi AP: start FAILED (attempt %d/3)\n", attempt);
      delay(200);
    }
  }
  WiFi.setSleep(false); // Lowest latency Wi-Fi

  if (apOk) {
    Serial.print("WiFi AP started! SSID: \"");
    Serial.print(AP_SSID);
    Serial.print("\" | IP: http://");
    Serial.print(WiFi.softAPIP());
    Serial.println("/");
  } else {
    Serial.println("WiFi AP: could NOT start. Check power supply and board settings.");
  }

  // 4. Start HTTP Control Server on Core 1
  startWebServer();

  // 5. Launch high-priority Flight Task pinned to Core 0 (200 Hz)
  xTaskCreatePinnedToCore(
    flightTask,
    "flight_loop",
    FLIGHT_TASK_STACK,
    nullptr,
    FLIGHT_TASK_PRIO,
    nullptr,
    FLIGHT_TASK_CORE
  );
  Serial.println("Flight Task: Created on Core 0 (200 Hz)");
  Serial.println("Ready! Connect phone to 'Nafasam' Wi-Fi and open 192.168.4.1\n");
}

void loop() {
  // Read battery voltage periodically
  g_vbat = readBatteryVoltage();

  // Bench Diagnostics (printed at 2 Hz)
  Serial.printf("[TELEM] Clients:%d | Bat:%.2fV | IMU:%s | Arm:%s | Roll:%5.1f Pitch:%5.1f | M1:%.2f M2:%.2f M3:%.2f M4:%.2f\n",
                WiFi.softAPgetStationNum(),
                g_vbat,
                g_imuOk ? "OK" : "NO",
                g_armedActive ? "ARMED" : "DISARM",
                g_dbgRoll, g_dbgPitch,
                g_dbgMotor[M_FL], g_dbgMotor[M_FR], g_dbgMotor[M_RL], g_dbgMotor[M_RR]);

  delay(500);
}

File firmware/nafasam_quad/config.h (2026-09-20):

#pragma once
#include <Arduino.h>

// ============================================================================
// Nafasam Mini Quad - Configuration & Hardware Pin Mapping
// Original PCB target: ESP32-S3-MINI-1-N4R2, DroneFC PCB Revision A0
// Pin map below is CUSTOMISED: motors 23/22/35/34, IMU 18/19/21
// Coreless Brushed Motors: 8520 (3.7V nominal, 1S LiPo)
// IMU: InvenSense MPU-6050 (QFN-24 bare chip on I2C address 0x68)
// ============================================================================

// ---------------- WiFi Access Point ----------------
#define AP_SSID             "Nafasam"
#define AP_PASSWORD         ""             // Empty = open network; otherwise 8+ chars
#define AP_CHANNEL          1
#define AP_MAX_CONN         4

// ---------------- I2C & IMU (MPU-6050) ----------------
// Custom wiring: IMU_SDA -> GPIO 18, IMU_SCL -> GPIO 19, IMU_INT -> GPIO 21
#define PIN_I2C_SDA         18
#define PIN_I2C_SCL         19
#define PIN_IMU_INT         21             // IMU INT (defined, not used by the firmware)
#define DRONE_IMU_I2C_ADDR  0x68           // MPU-6050 address
#define I2C_FREQ_HZ         400000         // 400 kHz Fast Mode
#define I2C_TIMEOUT_MS      10

// ---------------- Motors (8520 Brushed Coreless) ----------------
// Low-side AO3400A MOSFET switches on DroneFC PCB:
// Motor 1 (J4): Front-Left  (FL) - Clockwise (CW)          -> GPIO 23 (PWM1)
// Motor 2 (J5): Front-Right (FR) - Counter-Clockwise (CCW) -> GPIO 22 (PWM2)
// Motor 3 (J6): Rear-Left   (RL) - Counter-Clockwise (CCW) -> GPIO 35 (PWM3)
// Motor 4 (J7): Rear-Right  (RR) - Clockwise (CW)          -> GPIO 34 (PWM4)
//
// NOTE: on the classic ESP32, GPIO 34..39 are INPUT-ONLY (no PWM/output), and on
// the ESP32-S3 GPIO 22..25 do not exist. The firmware checks this at boot and
// refuses to arm if a motor pin cannot drive an output.
#define PIN_MOTOR_FL        23             // Motor 1 (J4)
#define PIN_MOTOR_FR        22             // Motor 2 (J5)
#define PIN_MOTOR_RL        35             // Motor 3 (J6)
#define PIN_MOTOR_RR        34             // Motor 4 (J7)

// ---------------- Motor PWM Settings ----------------
// High frequency PWM (16 kHz) eliminates audible coil whine and drives 8520 motors efficiently
#define PWM_FREQ_HZ         16000
#define PWM_RES_BITS        10             // 10-bit resolution (0..1023)
#define PWM_MAX_DUTY        ((1 << PWM_RES_BITS) - 1)
#define MOTOR_MAX_THROTTLE  0.95f          // 95% ceiling for voltage/thermal safety margin

// ---------------- Battery Monitoring ----------------
// DroneFC PCB: VBAT_SENSE on GPIO 1 through 100k / 100k voltage divider (2:1 ratio)
#define PIN_BATTERY_ADC     1
#define BATTERY_DIVIDER_RATIO 2.0f
#define BATTERY_LOW_VOLTS   3.30f          // Low battery warning threshold
#define BATTERY_CRIT_VOLTS  3.10f          // Critical battery threshold

// ---------------- Flight Loop (Core 0 FreeRTOS Task) ----------------
#define LOOP_PERIOD_MS      5              // 200 Hz control loop (5 ms)
#define FLIGHT_TASK_CORE    0
#define FLIGHT_TASK_PRIO    10
#define FLIGHT_TASK_STACK   8192

#define COMPLEMENTARY_ALPHA 0.98f          // Gyro weight in complementary filter
#define MAX_TILT_DEG        25.0f          // Full stick = 25 degrees tilt
#define MAX_YAW_RATE_DPS    150.0f         // Full stick = 150 deg/s yaw rate
#define CRASH_ANGLE_DEG     65.0f          // Tilt past this threshold triggers emergency disarm

// ---------------- PID Stabilisation Tuning ----------------
#define KP_ANGLE            0.014f         // Proportional gain per degree of error
#define KI_ANGLE            0.008f         // Integral gain per degree-second
#define KD_ANGLE            0.0020f        // Derivative gain per deg/s of gyro angular rate
#define I_LIMIT             0.08f          // Anti-windup limit for angle integral
#define KP_YAW_RATE         0.003f         // Proportional gain per deg/s of yaw rate error
#define PID_OUT_LIMIT       0.35f          // Max mixer contribution for roll/pitch PID
#define YAW_OUT_LIMIT       0.20f          // Max mixer contribution for yaw PID

// ---------------- Safety & Failsafes ----------------
#define FAILSAFE_MS         500            // Disarm after 500 ms of command silence
#define THROTTLE_DEADBAND   3              // Throttle % below which motors stay idle/off
#define ARM_MAX_THROTTLE    5              // Refuse arming if throttle exceeds 5%
#define IMU_FAIL_LIMIT      5              // Consecutive IMU read failures before failsafe
#define IMU_RETRY_MS        500            // IMU reconnection retry period

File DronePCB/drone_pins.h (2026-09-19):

#pragma once
// Hardware mapping only. This file does not implement a flight controller.
// ESP32-S3-MINI-1-N4R2, DroneFC revision A0.
#define DRONE_MOTOR1_GPIO 39
#define DRONE_MOTOR2_GPIO 40
#define DRONE_MOTOR3_GPIO 41
#define DRONE_MOTOR4_GPIO 42
#define DRONE_BATTERY_ADC_GPIO 1
#define DRONE_IMU_SDA_GPIO 33
#define DRONE_IMU_SCL_GPIO 34
#define DRONE_IMU_INT_GPIO 21
#define DRONE_IMU_I2C_ADDRESS 0x68
#define DRONE_CAM_PWDN_GPIO 4
#define DRONE_CAM_RESET_GPIO (-1) // External RC pullup, no MCU reset line.
#define DRONE_CAM_SDA_GPIO 5
#define DRONE_CAM_SCL_GPIO 6
#define DRONE_CAM_XCLK_GPIO 7
#define DRONE_CAM_D0_GPIO 8
#define DRONE_CAM_D1_GPIO 9
#define DRONE_CAM_D2_GPIO 10
#define DRONE_CAM_D3_GPIO 11
#define DRONE_CAM_D4_GPIO 12
#define DRONE_CAM_D5_GPIO 13
#define DRONE_CAM_D6_GPIO 14
#define DRONE_CAM_D7_GPIO 15
#define DRONE_CAM_PCLK_GPIO 16
#define DRONE_CAM_HREF_GPIO 17
#define DRONE_CAM_VSYNC_GPIO 18
#define DRONE_UART_TX_GPIO 43
#define DRONE_UART_RX_GPIO 44
// Configure all motor outputs LOW before starting any peripherals.
// ADC division is nominally 2:1; calibrate against measured battery voltage.

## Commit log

2026-09-19 firmware: HTTP control, MPU6050 driver, PID flight task; new control page
    - ESP32 AP 'nafasm' with esp_http_server (/ and /control)
    - 200Hz flight task on core 0: complementary filter, PID, X mixer, PWM
    - register-level MPU6050 driver (no external library)
    - new touch control page with ARM button and help panel
    - protocol v2 docs, README update
2026-09-19 docs: add hardware wiring guide (ESP32, MPU6050, motors, battery)
2026-09-19 PCD designs
    [BOM.csv, DroneFC.dsn, DroneFC.kicad_pcb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]
